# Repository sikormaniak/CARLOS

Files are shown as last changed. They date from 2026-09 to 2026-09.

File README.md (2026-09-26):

# CARLOS

Repozytorium projektowe robota mobilnego z napędem mecanum, zrealizowanego w ramach pracy dyplomowej. Zawiera schematy elektroniczne i modele 3D (Altium Designer), pliki produkcyjne PCB (Gerber) oraz projekt oprogramowania wbudowanego (ESP-IDF).

## Struktura repozytorium

```
CARLOS/
├── design/     # schematy Altium Designer, modele 3D oraz dokumentacja PDF 3D
├── gerber/     # pliki produkcyjne PCB (Gerber)
└── software/   # oprogramowanie wbudowane (ESP-IDF)
```

## `design/` -- Altium Designer

Folder zawiera schematy elektroniczne, pliki 3D płytek oraz ich podgląd w formacie PDF 3D.

### Główny obwód drukowany

- `schemat.SchDoc` -- Schemat główny, integrujący wszystkie moduły
  - `ARGB.SchDoc` -- Sterowanie diodami adresowalnymi ARGB
  - `MCU_unit.SchDoc` -- Jednostka mikrokontrolera Waveshare ESP32-P4-Module
  - `connectors.SchDoc` -- Złącza zewnętrzne oraz zworki konfiguracyjne
  - `audio.SchDoc` -- Obsługa buzzera, głośnika oraz mikrofonu
  - `IMU.SchDoc` -- Konfiguracja żyroskopu oraz magnetometru
  - `Motor_SCH.SchDoc` -- Blok łączący funkcjonalność dla 4 silników szczotkowych
    - `DRV8837CDSGR.SchDoc` -- Konfiguracja mostka H -- DRV8837CDSGR
  - `microsd_card.SchDoc` -- Interfejs karty microSD
  - `USB_HS.SchDoc` -- Interfejs USB High-Speed
  - `CH342F.SchDoc` -- Konwerter USB-UART CH342F
  - `Power_block.SchDoc` -- LDO dla 5V oraz przetwornica BUCK dla 3,3V

### Doker baterii

- `main_IP5353.SchDoc` -- Schemat główny dokera

### Pliki 3D

- Modele 3D płytek PCB
- Dokumentacja PDF 3D -- interaktywny podgląd płytek, możliwy do otwarcia w Adobe Acrobat Reader

## `gerber/` -- Pliki wykonawcze

Zweryfikowane zamówienie w [JLCPCB](https://jlcpcb.com).

- `carlos_v0.1` -- Pliki gerber dla głównego PCB
- `slim_v3.2` -- Pliki gerber dla dokera baterii

## `software/` -- Oprogramowanie ESP-IDF

- `CMakeLists.txt` -- główny plik konfiguracyjny projektu
- `sdkconfig.defaults` -- domyślna konfiguracja projektu (docelowy mikrokontroler, dane sieci WiFi, adres i port agenta micro-ROS, przypisanie pinów silników)
- `partitions.csv` -- niestandardowa tabela partycji pamięci flash
- `main/CMakeLists.txt` -- plik konfiguracyjny komponentu głównego
- `main/Kconfig.projbuild` -- definicja opcji konfiguracyjnych projektu dostępnych w `menuconfig` (piny GPIO oraz grupy MCPWM dla czterech silników)
- `main/idf_component.yml` -- deklaracja zależności projektu, w tym komponentu `micro_ros_espidf_component`
- `main/robot_main.c` -- kod źródłowy realizujący obsługę odbiornika RC (protokół CRSF), kinematykę odwrotną napędu mecanum, sterowanie silnikami (PWM) oraz integrację z systemem micro-ROS

### Konfiguracja pinów silników

Przypisanie pinów nie jest zapisane na stałe w kodzie -- definiuje je `main/Kconfig.projbuild`, a wartości trafiają do `sdkconfig` jako makra `CONFIG_WHEEL_*`. Zmiana pinów nie wymaga edycji kodu źródłowego:

```bash
idf.py menuconfig   # menu: CARLOS - piny silników
```

| Koło | IN1 | IN2 | Grupa MCPWM |
|---|-----|-----|---|
| Przednie lewe (FL) | GPIO 5  | GPIO 20 | 0 |
| Przednie prawe (FR) | GPIO 32 | GPIO 33 | 0 |
| Tylne lewe (BL) | GPIO 3  | GPIO 4  | 1 |
| Tylne prawe (BR) | GPIO 1  | GPIO 2  | 1 |

> Zmiany w `sdkconfig.defaults` są uwzględniane dopiero po usunięciu pliku `sdkconfig` lub wykonaniu `idf.py fullclean`.

### Wymagania

- ESP-IDF v5.5 z toolchainem dla ESP32-P4
- Linux lub WSL (Ubuntu)

Pakiety systemowe (kompilator hosta, potrzebny do zbudowania narzędzi micro-ROS):

```bash
sudo apt update
sudo apt install build-essential git
```

Pakiety Pythona dla micro-ROS (colcon i zależności), instalowane w środowisku Pythona ESP-IDF:

```bash
. $IDF_PATH/export.sh
python -m pip install catkin_pkg lark-parser colcon-common-extensions empy==3.3.4
```

> Wersja `empy==3.3.4` jest wymagana -- nowsze wersje (4.x) nie są kompatybilne z budowaniem micro-ROS.

Weryfikacja instalacji:

```bash
python -c "import catkin_pkg, lark, em, colcon_core; print('OK')"
```

### Budowanie projektu

```bash
cd software
idf.py set-target esp32p4
idf.py menuconfig   # konfiguracja WiFi, adresu agenta micro-ROS oraz pinów silników
idf.py build flash monitor
```

Pierwsze budowanie trwa kilka minut -- komponent micro-ROS jest pobierany automatycznie do `managed_components/` i kompilowany jako biblioteka `libmicroros.a`. Kolejne buildy korzystają z gotowej biblioteki.

> Główny `CMakeLists.txt` zawiera poprawkę zmiennej `PATH`, która usuwa z niej katalogi z asemblerami toolchainów ESP. Bez niej systemowy `gcc` używany przez micro-ROS wybierałby niewłaściwy asembler (`as: unrecognized option '--64'`).

W razie ponownego budowania micro-ROS od zera:

```bash
rm -rf build managed_components/micro-ros__micro_ros_espidf_component/micro_ros_dev managed_components/micro-ros__micro_ros_espidf_component/micro_ros_src
idf.py build
```

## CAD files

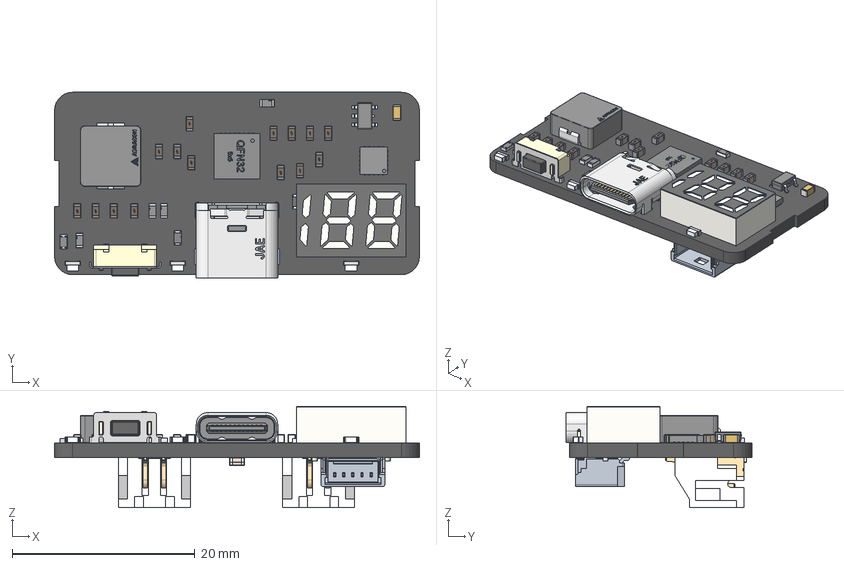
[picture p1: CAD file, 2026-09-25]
design/Battery Docker/Docker.stp
40.0 x 20.3 x 11.1 mm
RES0603 x 2
BODY-SOT
LEAD-SOT x 5
LEAD-DUMMY
188???
Samsung logo x 16
Panasonic Logo
ThermalPin
PinsArrayLR
PinsArrayTB
RT0603BRD07104KL_Ceramic
RT0603BRD07104KL_Terminal x 2
RT0603BRD07104KL_Coating
RT0603BRD07104KL_Logo
Yageo Logo x 5
QFN32-5x5
terminal
logo
TL 3330 Tactile Button
JST-S2B-PH-SM4-TB x 2
K3D-DX07S024JJ2-V1_JAE_Proprietary
Notch
pins

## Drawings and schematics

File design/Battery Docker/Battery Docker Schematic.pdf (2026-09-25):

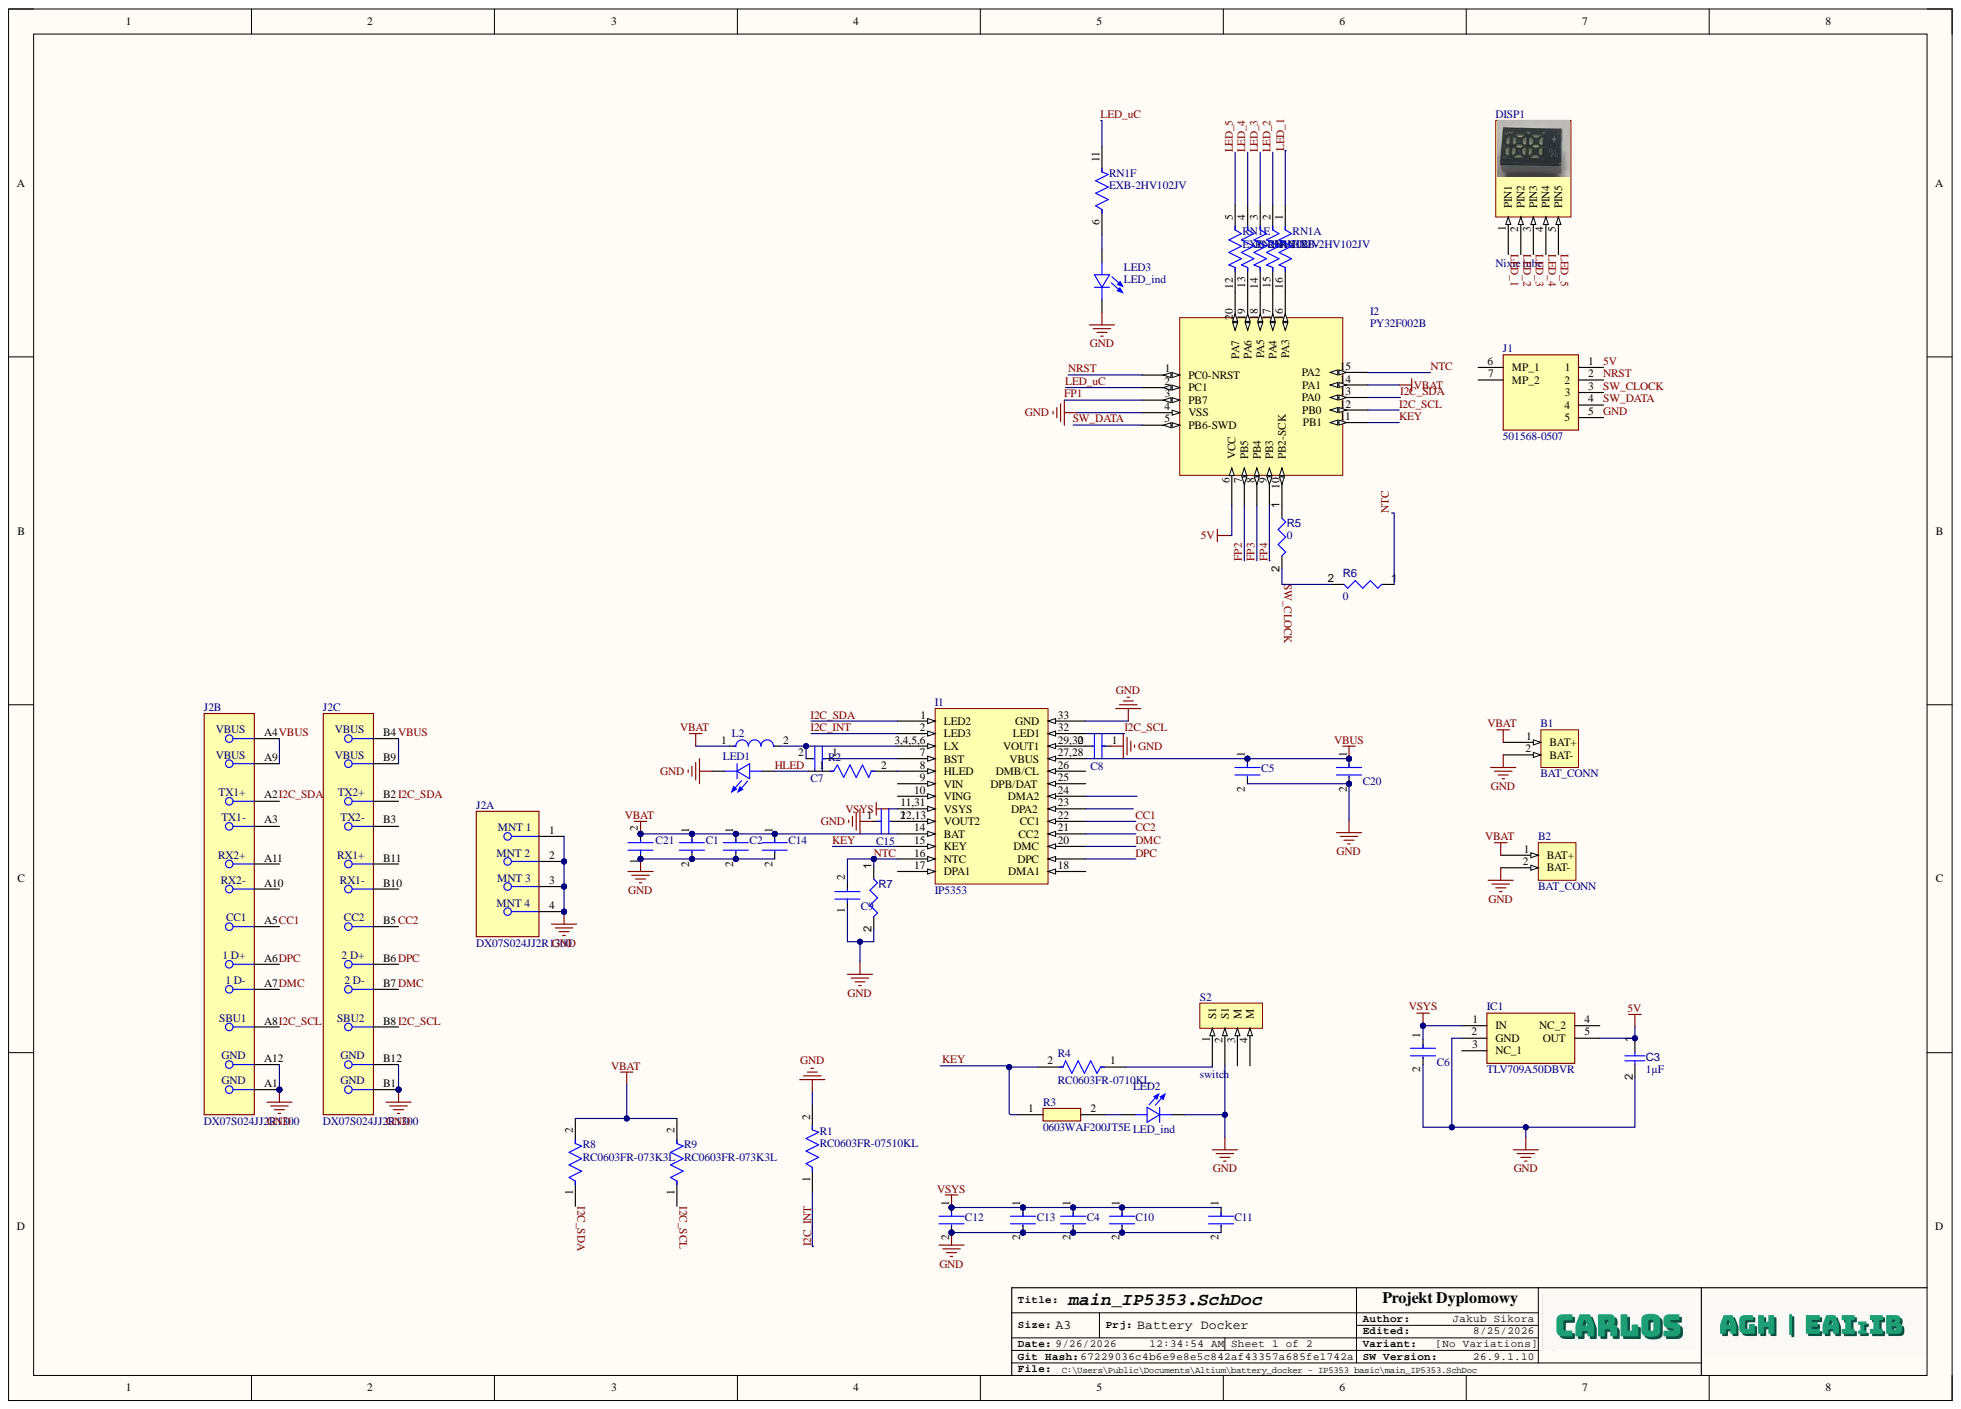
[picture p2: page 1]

12:34:54 AM Date: | Variant: [No Variations] | * 9/26/2026

Git Hash:67229036c4b6e9e8e5c842af43357a685fe1742a

File: C:\Users\Public\Documents\Altium\battery_docker - IP5353 basic\main_IP5353.SchDoc

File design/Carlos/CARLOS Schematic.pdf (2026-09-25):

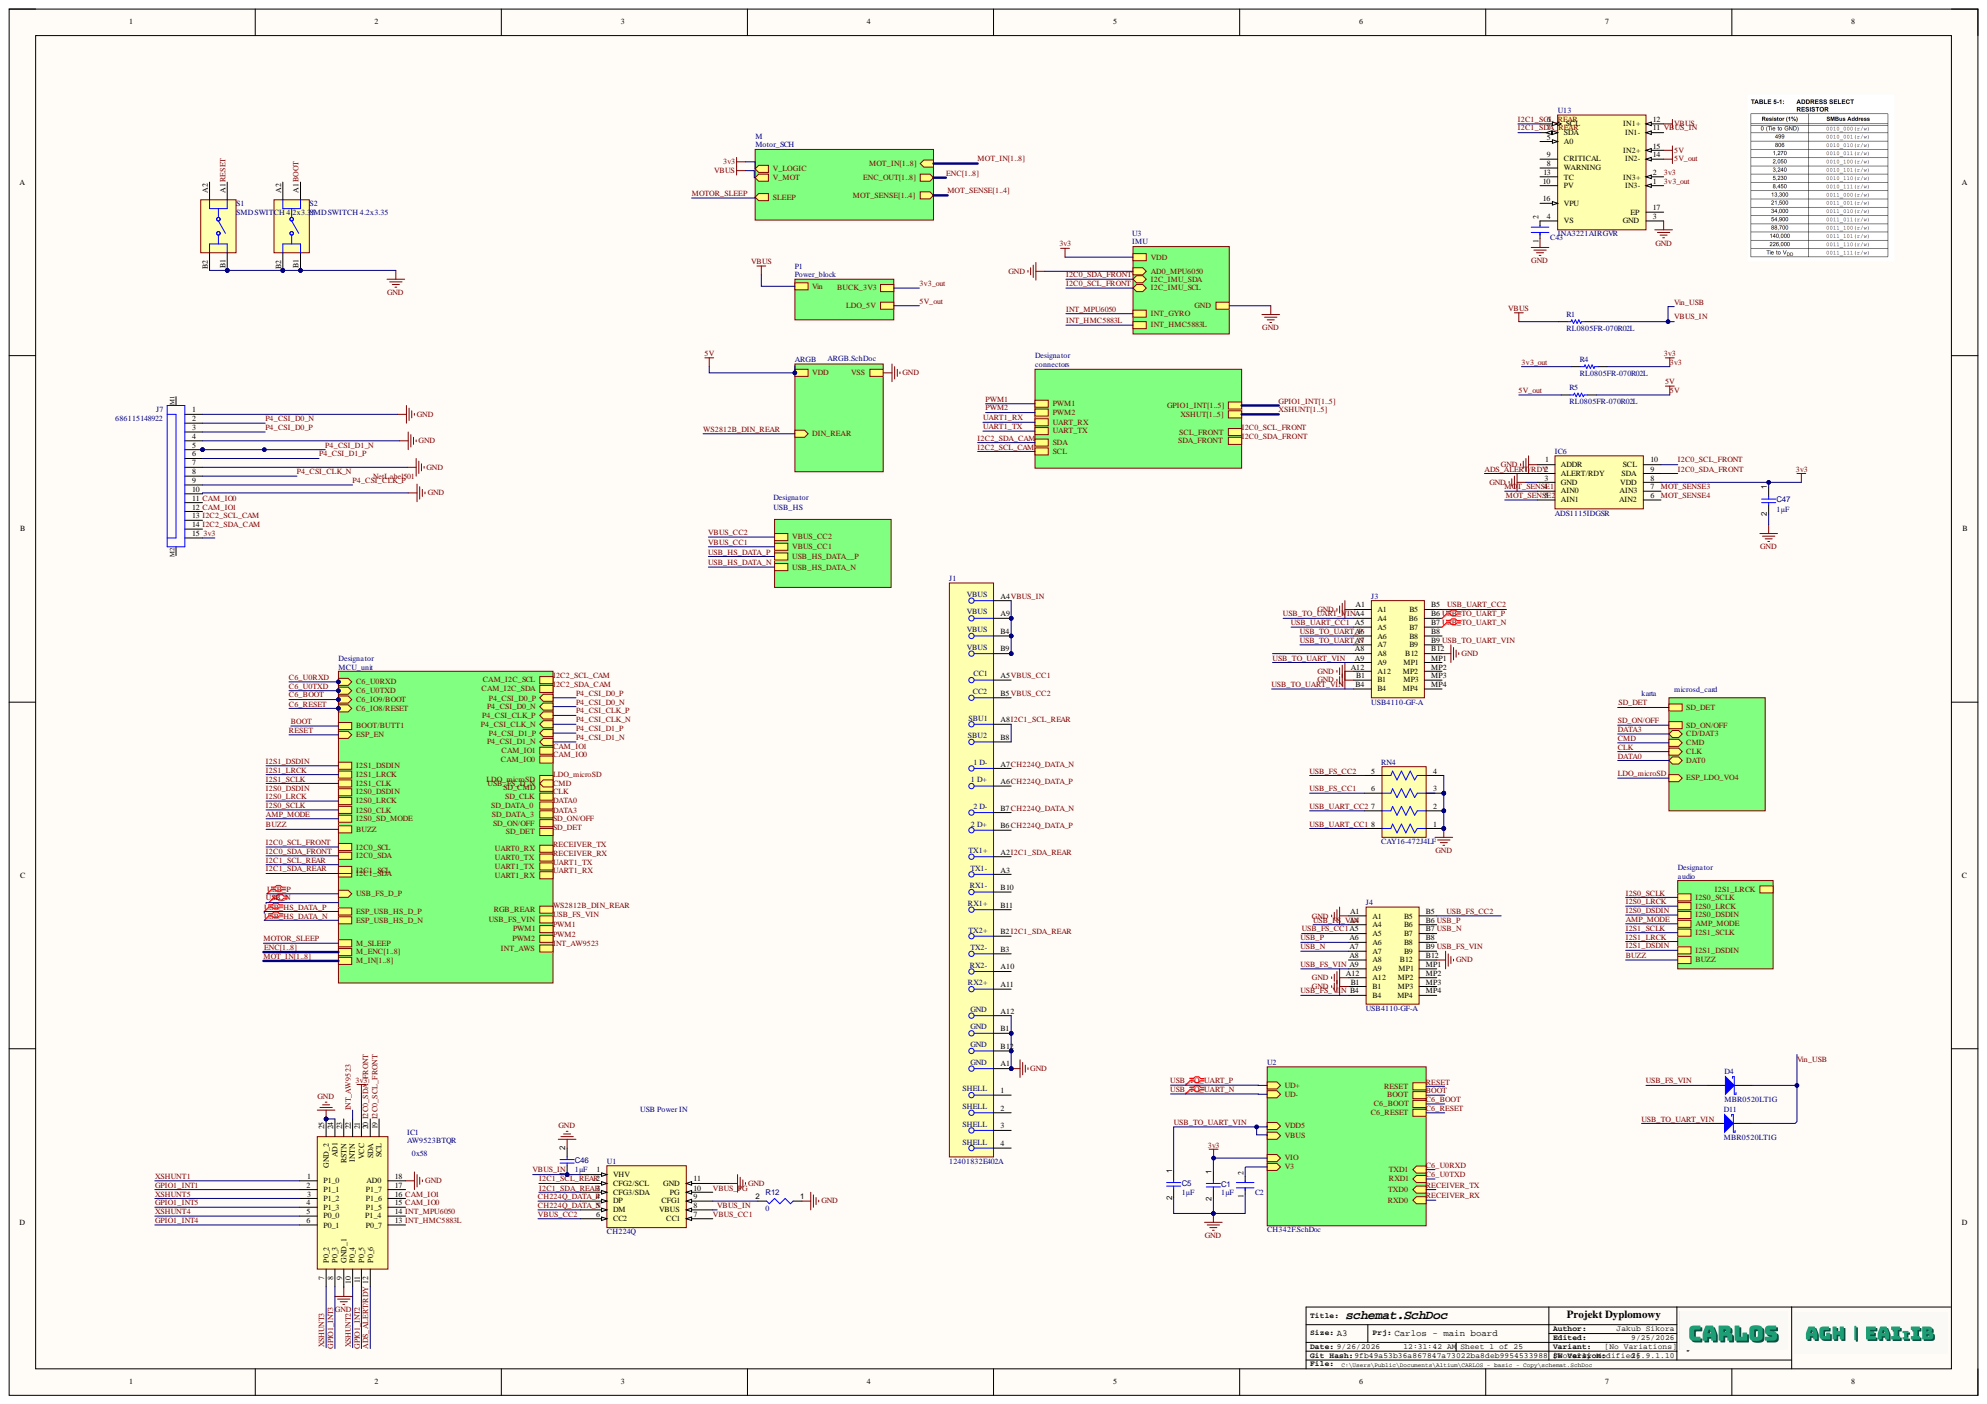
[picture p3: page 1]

Size: A3 | Prj: Carlos - main board | Author: Jakub Sikora

Date: | | Variant: [No Variations]

File: C:\Users\Public\Documents\Altium\CARLOS - basic - Copy\schemat.SchDoc

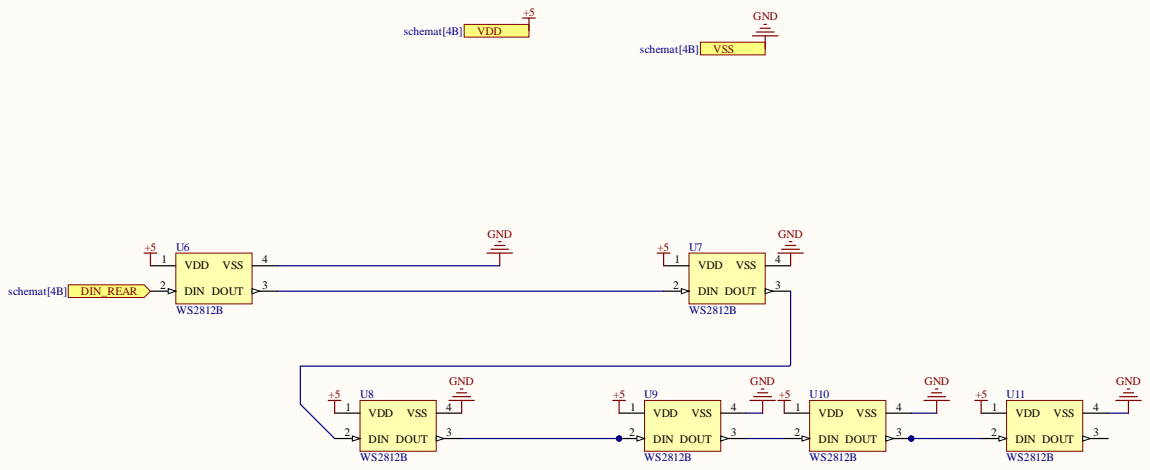
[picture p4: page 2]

Prj: Carlos - main board

Git Hash: 9fb49a53b36a867847a73022ba8deb9954533988

File: C:\Users\Public\Documents\Altium\CARLOS - basic - Copy\ARGB.SchDoc

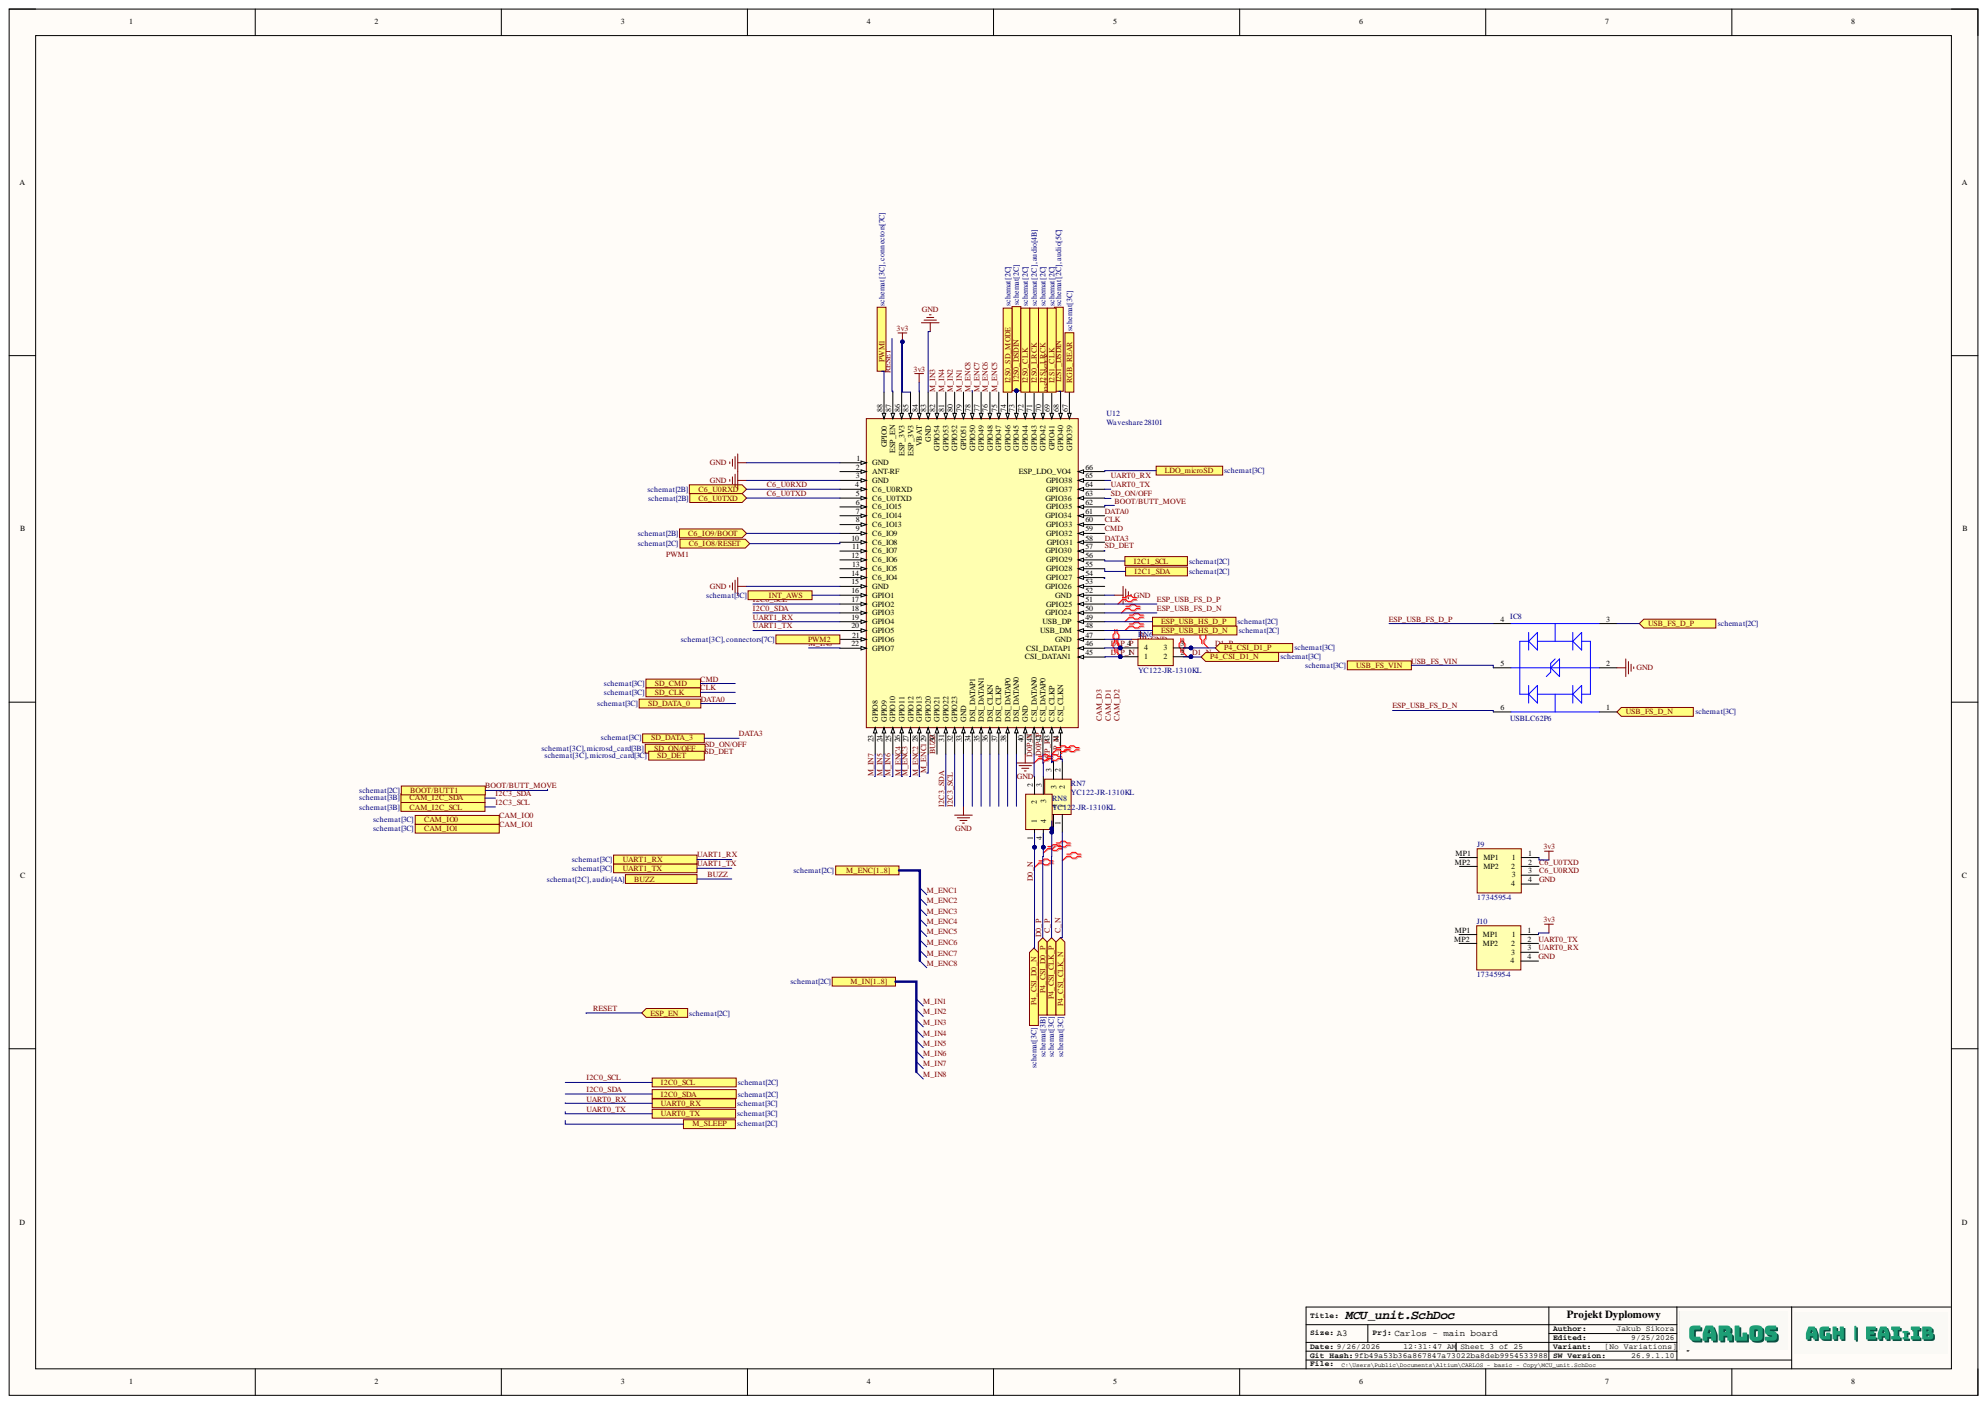
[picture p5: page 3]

Prj: Carlos - main board

Git Hash:9fb49a53b36a867847a73022ba8deb9954533988
File: C:\Users\Public\Documents\Altium\CARLOS - basic - Copy\MCU_unit.SchDoc

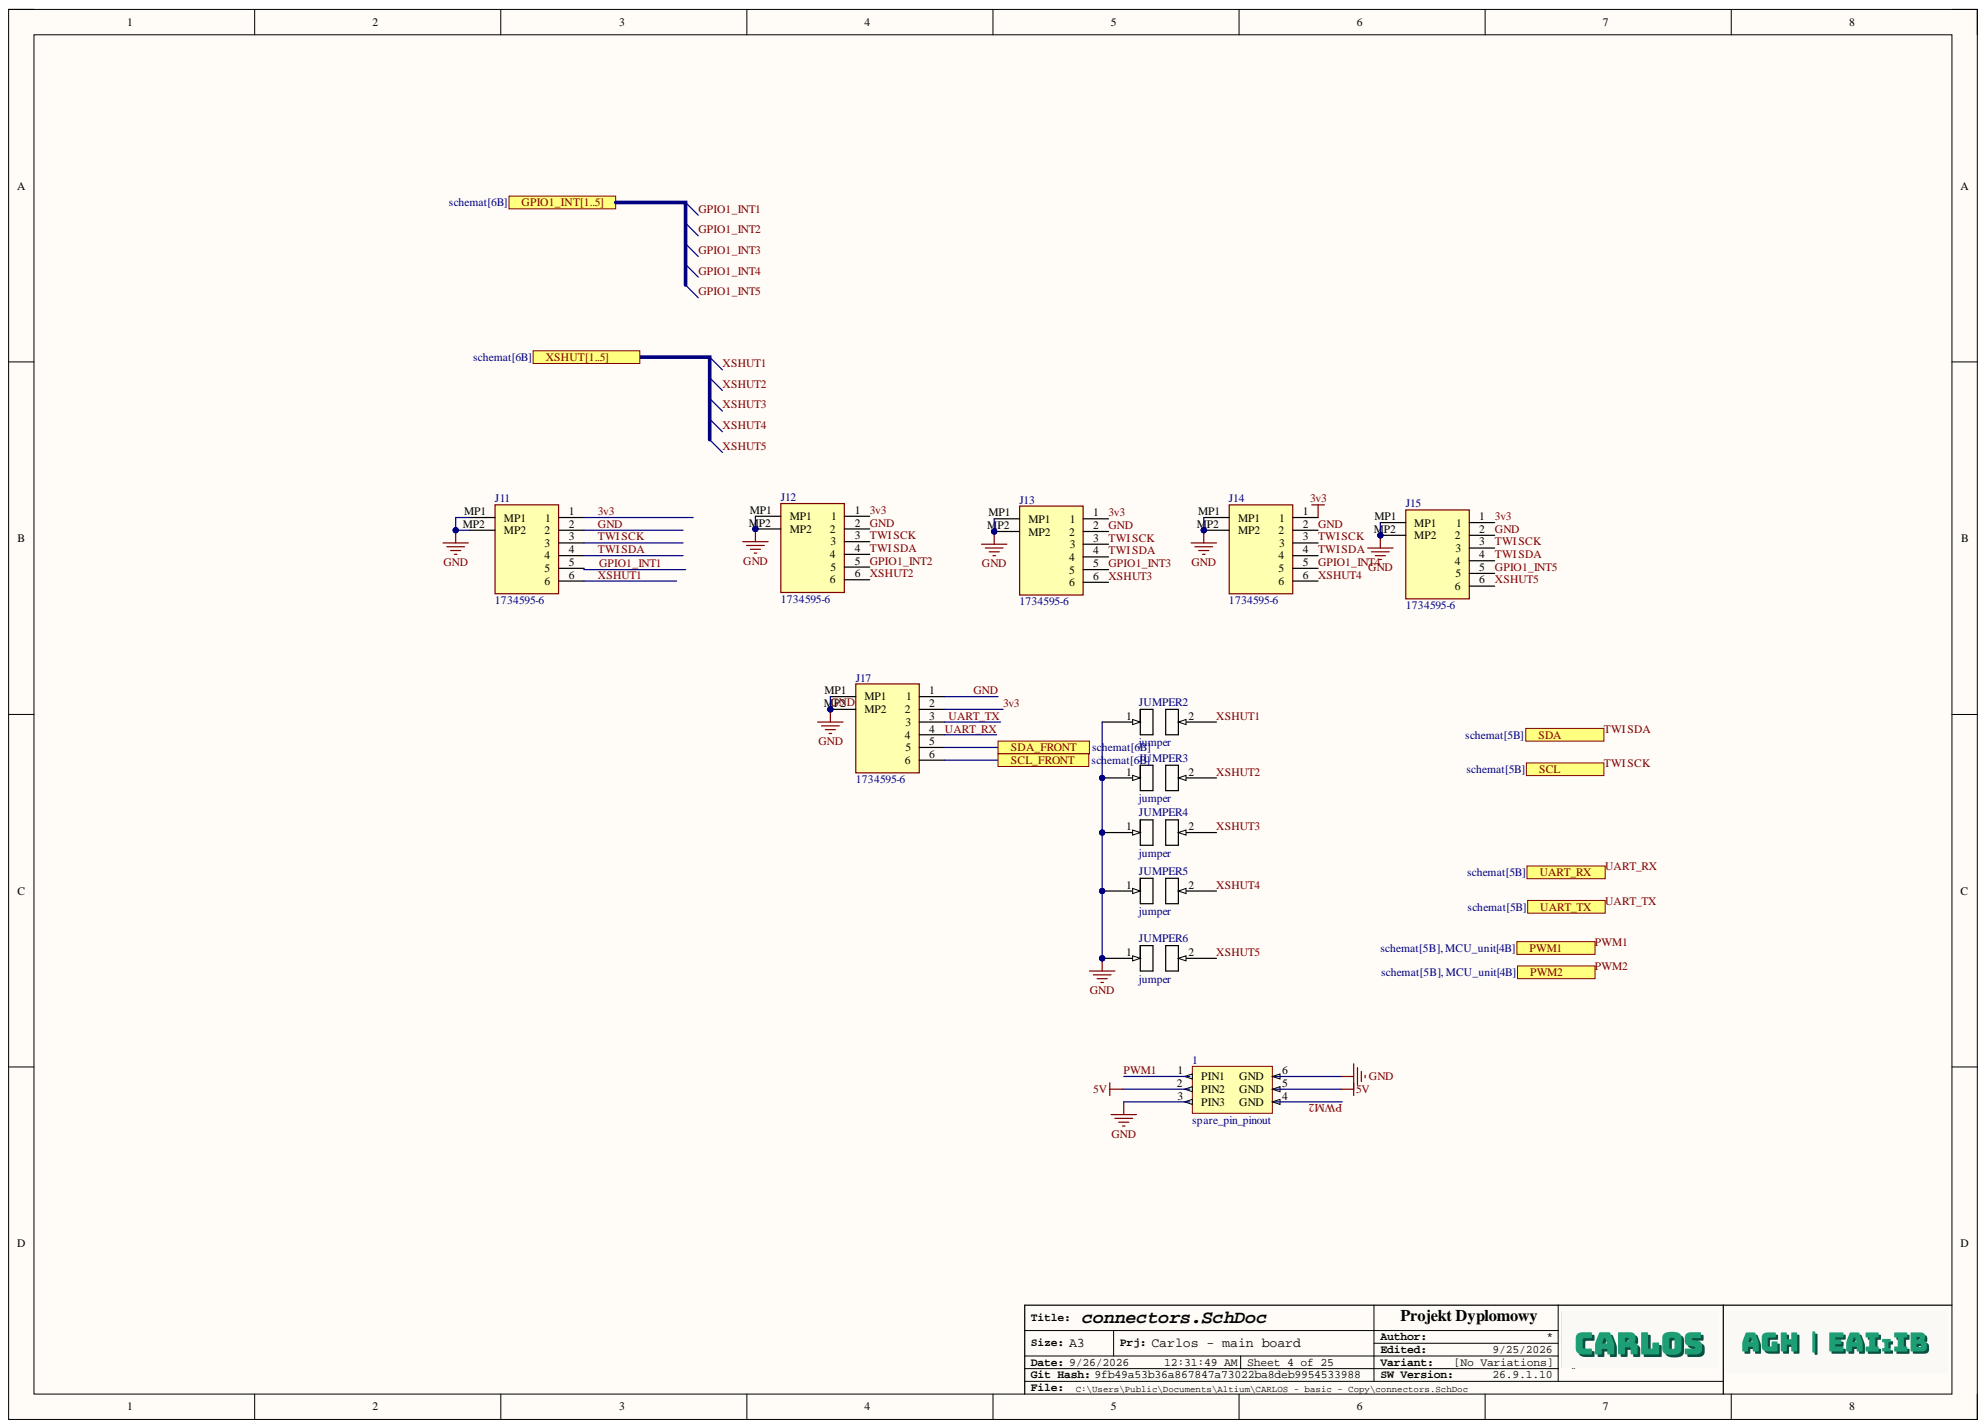
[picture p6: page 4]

Prj: Carlos - main board

File: C:\Users\Public\Documents\Altium\CARLOS - basic - Copy\connectors.SchDoc

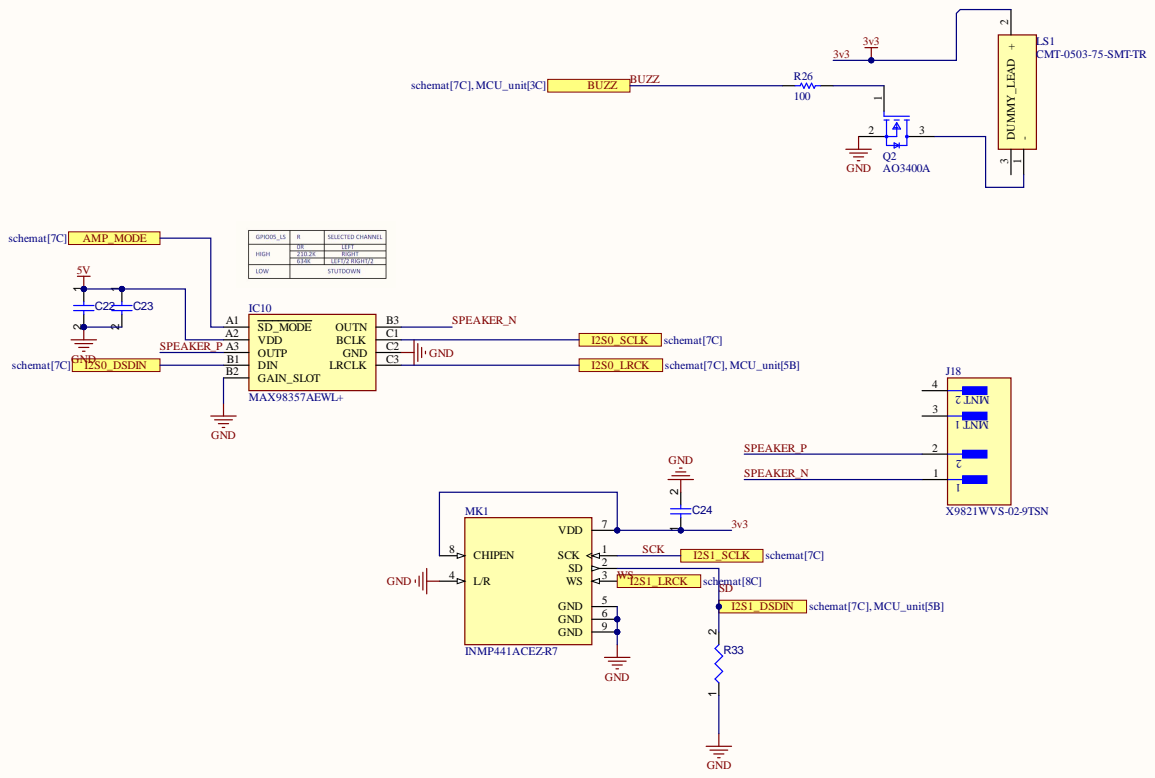
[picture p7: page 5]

Prj: Carlos - main board

File: C:\Users\Public\Documents\Altium\CARLOS - basic - Copy\audio.SchDoc

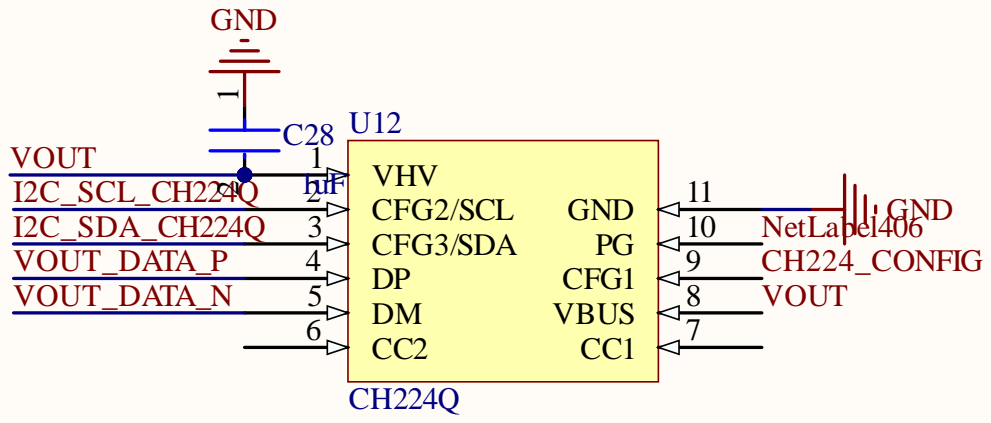
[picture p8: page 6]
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

: C:\Users\Public\Documents\Altium\CARLOS - basic - Copy\CH224Q.SchDoc

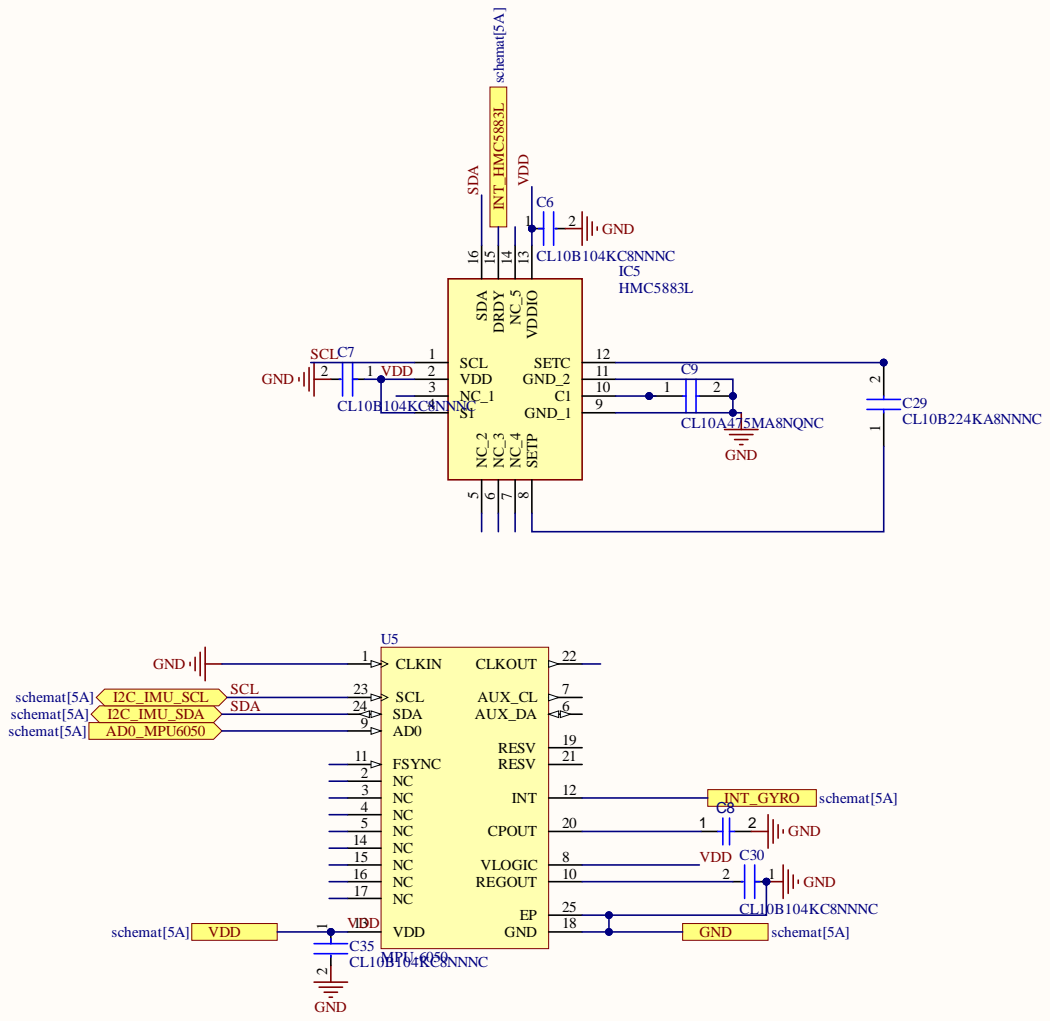
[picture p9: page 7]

VDD 2 NC_1 3 S1 4 | C9

Prj: Carlos - main board

File: C:\Users\Public\Documents\Altium\CARLOS - basic - Copy\IMU.SchDoc

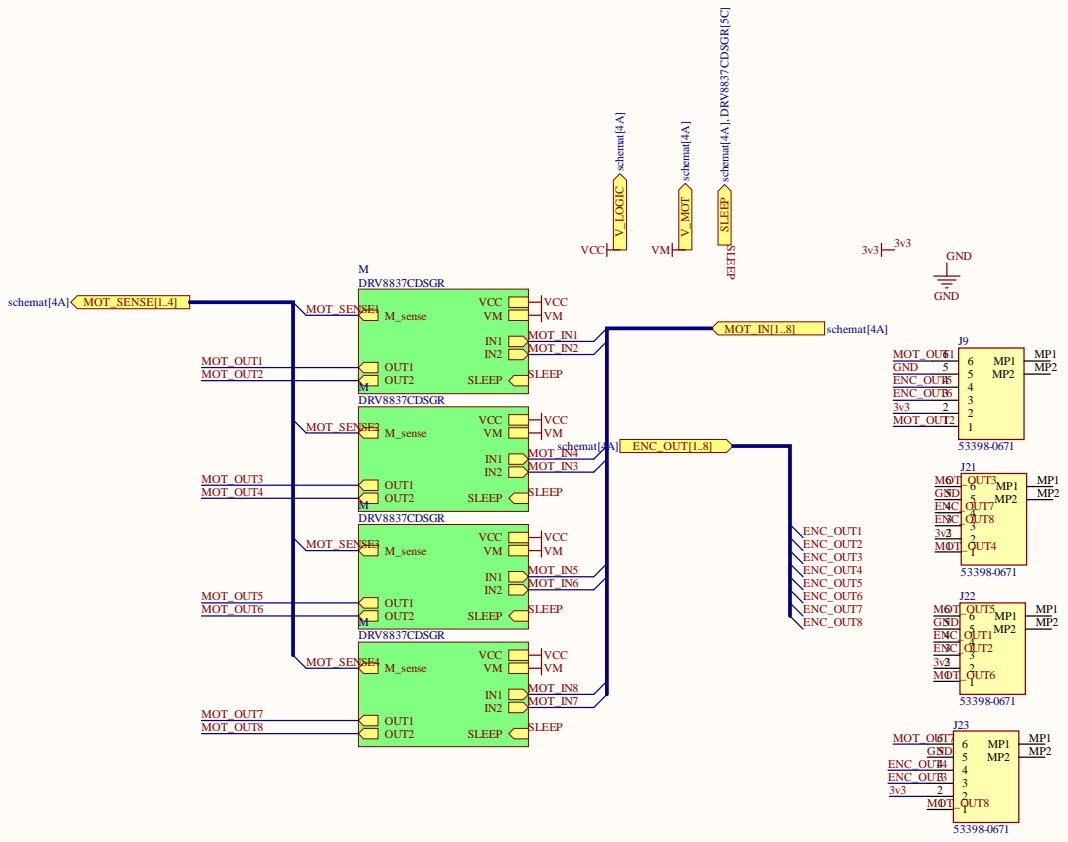
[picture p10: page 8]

Prj: Carlos - main board

File: C:\Users\Public\Documents\Altium\CARLOS - basic - Copy\Motor_SCH.SchDoc

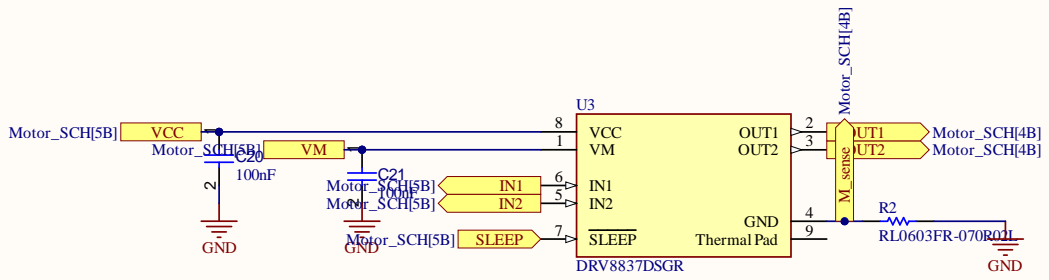
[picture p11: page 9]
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

: C:\Users\Public\Documents\Altium\CARLOS - basic - Copy\DRV8837CDSGR.SchDoc

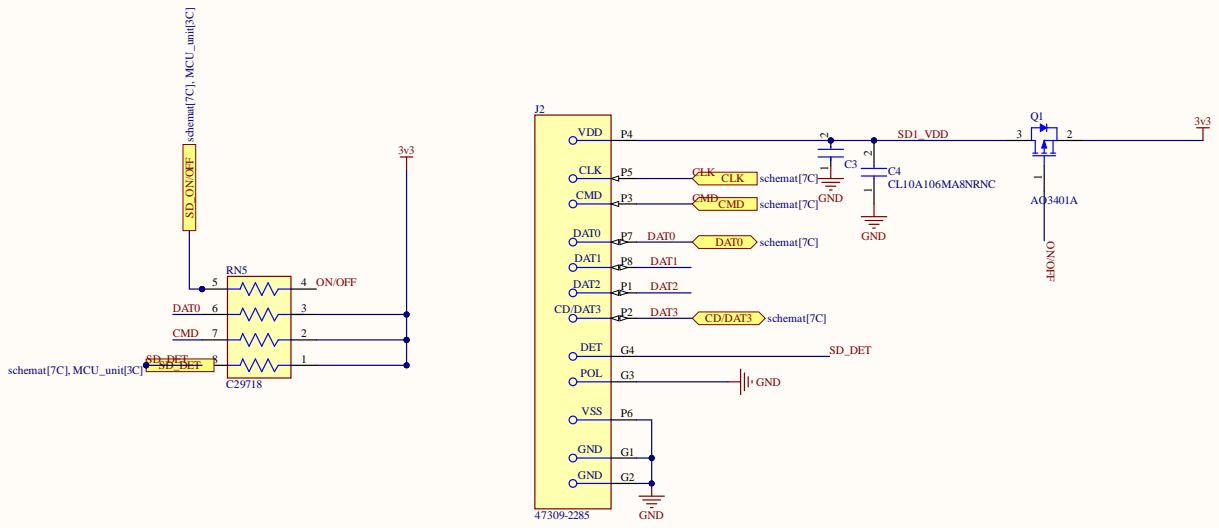
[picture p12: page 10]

MD VDD CLK VSS DAT0 DAT1

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

: C:\Users\Public\Documents\Altium\CARLOS - basic - Copy\microsd_card.SchDoc

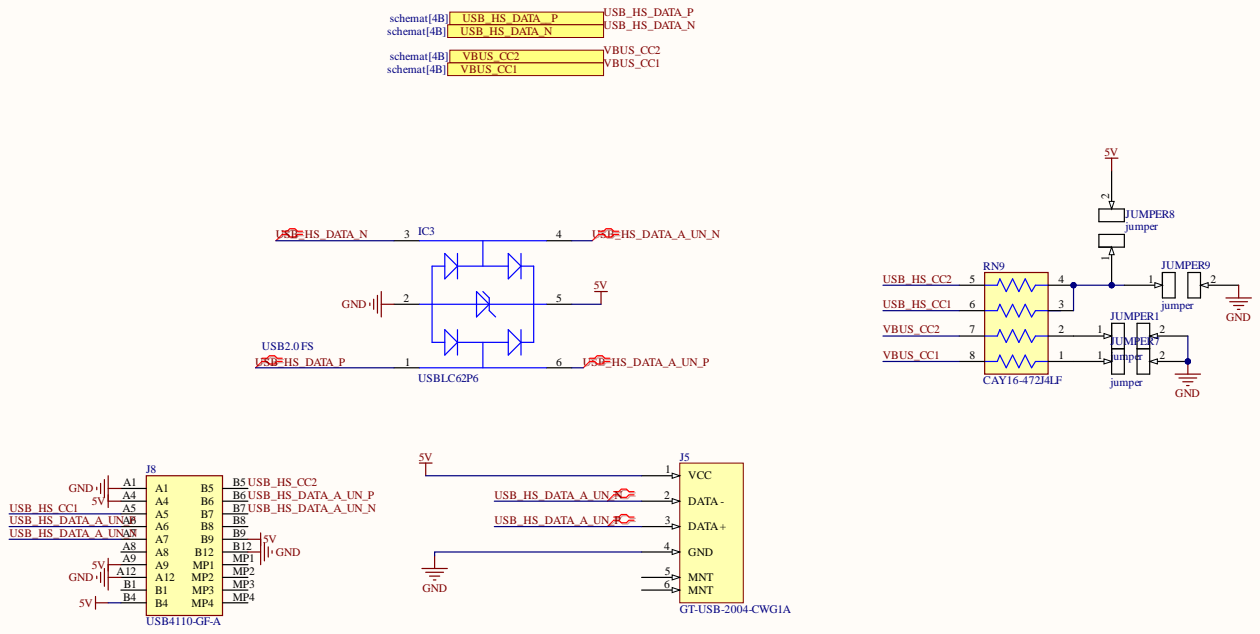
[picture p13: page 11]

A1 A1 | USB_HS_DATA_A_UN_N | DATA - 2

A5 A5 | USB_HS_DATA_A_UN_P | DATA+ 3

Prj: Carlos - main board

File: C:\Users\Public\Documents\Altium\CARLOS - basic - Copy\USB_HS.SchDoc


Prj: Carlos - main board

File: C:\Users\Public\Documents\Altium\CARLOS - basic - Copy\CH342F.SchDoc


Prj: Carlos - main board

File: C:\Users\Public\Documents\Altium\CARLOS - basic - Copy\Power_block.SchDoc

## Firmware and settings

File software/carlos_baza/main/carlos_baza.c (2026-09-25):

/*
 * Sterowanie platformą mecanum (4x N20, 4x DRV8833) z dwoma
 * niezależnymi źródłami komend prędkości:
 *
 *   1) micro-ROS  -> subskrybent /cmd_vel (geometry_msgs/msg/Twist)
 *   2) ELRS/CRSF  -> odbiornik RC podłączony przez UART (kanał zapasowy /
 *                    ręczne sterowanie / failsafe, NIEZALEŻNY od WiFi)
 *
 * Priorytet: gdy z odbiornika RC napływają świeże ramki ORAZ przełącznik
 * (kanał AUX, domyślnie CH5) jest w pozycji "override", pilot ma
 * pierwszeństwo nad komendami z ROS 2 -- to standardowe zabezpieczenie
 * (failsafe) w systemach zdalnie sterowanych. W przeciwnym razie robot
 * jedzie zgodnie z ostatnią komendą /cmd_vel; jeśli obie komendy są
 * nieaktualne (timeout), robot się zatrzymuje.
 *
 * UWAGA -- WERSJA BEZ ENKODERÓW:
 * Ze względu na niedobór dostępnych pinów GPIO enkodery kwadraturowe
 * (PCNT) oraz oparta na nich pętla regulacji PID zostały usunięte.
 * Sterowanie silnikami jest teraz w układzie otwartym (feedforward) --
 * zadana prędkość koła (rad/s) jest bezpośrednio, liniowo przeliczana
 * na wypełnienie PWM względem zakładanej maksymalnej prędkości obrotowej
 * silnika (MAX_WHEEL_SPEED_RAD_S), bez żadnej korekcji na podstawie
 * rzeczywiście zmierzonej prędkości. Konsekwencje praktyczne:
 *   - brak kompensacji różnic między silnikami (tolerancje produkcyjne,
 *     różne obciążenie każdego koła) -- robot może ciągnąć w bok,
 *   - brak kompensacji spadku napięcia baterii w czasie,
 *   - brak możliwości precyzyjnej odometrii (nie ma zliczania impulsów).
 *
 * WSZYSTKIE WARTOŚCI OZNACZONE "-- DOPASOWAĆ" WYMAGAJĄ WERYFIKACJI
 * WZGLĘDEM RZECZYWISTEGO SPRZĘTU PRZED URUCHOMIENIEM.
 */
#include "sdkconfig.h"
#include <stdio.h>
#include <string.h>
#include <math.h>
#include <inttypes.h>

#include "freertos/FreeRTOS.h"
#include "freertos/task.h"
#include "freertos/semphr.h"
#include "esp_log.h"
#include "esp_err.h"

#include "driver/uart.h"
#include "bdc_motor.h"

#include <rcl/rcl.h>
#include <rclc/rclc.h>
#include <rclc/executor.h>
#include <geometry_msgs/msg/twist.h>
#include <std_msgs/msg/string.h>
#include <rmw_microros/rmw_microros.h>
#include <uros_network_interfaces.h>

static const char *TAG = "robot";

/* ==========================================================================
 *  Makra pomocnicze micro-ROS
 * ========================================================================== */
#define RCCHECK(fn) do { \
    rcl_ret_t temp_rc = fn; \
    if ((temp_rc != RCL_RET_OK)) { \
        ESP_LOGE(TAG, "Blad RCL w linii %d: %d. Restart.", __LINE__, (int)temp_rc); \
        vTaskDelete(NULL); \
    } \
} while (0)

#define RCSOFTCHECK(fn) do { \
    rcl_ret_t temp_rc = fn; \
    if ((temp_rc != RCL_RET_OK)) { \
        ESP_LOGW(TAG, "Blad RCL (niekrytyczny) w linii %d: %d", __LINE__, (int)temp_rc); \
    } \
} while (0)

/* ==========================================================================
 *  Parametry PWM / MCPWM (sterowanie DRV8833 przez wejścia IN1/IN2)
 * ========================================================================== */
#define BDC_MCPWM_TIMER_RESOLUTION_HZ  10000000    // 10 MHz -> 1 tick = 0.1 us
#define BDC_MCPWM_FREQ_HZ              25000       // 25 kHz PWM
#define BDC_MCPWM_DUTY_TICK_MAX        (BDC_MCPWM_TIMER_RESOLUTION_HZ / BDC_MCPWM_FREQ_HZ)

/* ==========================================================================
 *  Sterowanie otwarte (feedforward) -- bez enkoderów / PID
 * ========================================================================== */
#define CONTROL_LOOP_PERIOD_MS         20          // 50 Hz

// Maksymalna prędkość obrotowa koła (rad/s) przy pełnym wypełnieniu PWM,
// odpowiadająca prędkości obrotowej wyjścia przekładni N20 bez obciążenia.
// -- DOPASOWAĆ na podstawie danych katalogowych silnika N20 (RPM przy
// zasilaniu nominalnym) przeliczonych na rad/s: rad/s = RPM * 2*pi/60.
#define MAX_WHEEL_SPEED_RAD_S          44.0f       // 420 RPM -> 43.98 rad/s, ale w praktyce przy obciążeniu i spadku napięcia

/* ==========================================================================
 *  Geometria platformy mecanum (wzory z rozdziału "Ruch")
 * ========================================================================== */
#define WHEEL_RADIUS_M                 0.029f      // 58 mm średnicy koła -> 29 mm promienia
#define WHEEL_LX_M                     0.040f      // 40 mm odległości osi koła od środka platformy wzdłuż osi X (przód-tył)
#define WHEEL_LY_M                     0.0725f      // 72.5 mm odległości osi koła od środka platformy wzdłuż osi Y (lewo-prawo)

/* ==========================================================================
 *  Limity prędkości platformy (skalowanie wychyleń drążków RC)
 * ========================================================================== */
#define MAX_LINEAR_SPEED_MPS           2.0f        // -- DOPASOWAĆ
#define MAX_ANGULAR_SPEED_RADPS        8.0f        // -- DOPASOWAĆ (teoretyczny sufit z geometrii ~11.3 rad/s;
                                                    // 8.0 daje solidny margines duty na pokonanie oporu obrotu
                                                    // w miejscu, ktory jest wiekszy niz przy jezdzie na wprost)

/* ==========================================================================
 *  Bezpieczeństwo -- timeouty utraty łączności (failsafe)
 * ========================================================================== */
#define CRSF_LINK_TIMEOUT_MS           500         // po tym czasie RC uznawane za "martwe"
#define CMD_VEL_TIMEOUT_MS             1000        // po tym czasie /cmd_vel uznawane za "martwe"

typedef enum {
    WHEEL_FL = 0,
    WHEEL_FR,
    WHEEL_BL,
    WHEEL_BR,
    WHEEL_COUNT,
} wheel_id_t;

static const char *wheel_name[WHEEL_COUNT] = { "FL", "FR", "BL", "BR" };

/* Piny DRV8833 -- DOPASOWAĆ do rzeczywistego PCB */
typedef struct {
    int pwm_in1_gpio;
    int pwm_in2_gpio;
    int mcpwm_group_id;
} wheel_pin_config_t;

static const wheel_pin_config_t wheel_pins[WHEEL_COUNT] = {
    [WHEEL_FL] = { .pwm_in1_gpio = CONFIG_WHEEL_FL_IN1_GPIO, .pwm_in2_gpio = CONFIG_WHEEL_FL_IN2_GPIO, .mcpwm_group_id = CONFIG_WHEEL_FL_MCPWM_GROUP },
    [WHEEL_FR] = { .pwm_in1_gpio = CONFIG_WHEEL_FR_IN1_GPIO, .pwm_in2_gpio = CONFIG_WHEEL_FR_IN2_GPIO, .mcpwm_group_id = CONFIG_WHEEL_FR_MCPWM_GROUP },
    [WHEEL_BL] = { .pwm_in1_gpio = CONFIG_WHEEL_BL_IN1_GPIO, .pwm_in2_gpio = CONFIG_WHEEL_BL_IN2_GPIO, .mcpwm_group_id = CONFIG_WHEEL_BL_MCPWM_GROUP },
    [WHEEL_BR] = { .pwm_in1_gpio = CONFIG_WHEEL_BR_IN1_GPIO, .pwm_in2_gpio = CONFIG_WHEEL_BR_IN2_GPIO, .mcpwm_group_id = CONFIG_WHEEL_BR_MCPWM_GROUP },
};

typedef struct {
    bdc_motor_handle_t motor;
    float target_speed_rad_s;
} wheel_ctx_t;

static wheel_ctx_t wheels[WHEEL_COUNT];

/* ==========================================================================
 *  Wspólny stan komend prędkości (chroniony mutexem) -- dwa niezależne
 *  źródła: micro-ROS (/cmd_vel) i CRSF (RC), plus znaczniki czasu ostatniej
 *  aktualizacji, wykorzystywane do wykrywania utraty łączności.
 * ========================================================================== */
typedef struct {
    float vx;
    float vy;
    float omega;
    TickType_t last_update_tick;
} velocity_command_t;

static SemaphoreHandle_t cmd_mutex;
static velocity_command_t cmd_vel_from_ros = { 0 };
static velocity_command_t cmd_vel_from_rc  = { 0 };
static volatile bool      rc_override_switch_on = false;
static volatile bool      full_power_test_on = false;

/* ==========================================================================
 *  Biezacy aktywny tryb sterowania -- do podgladu po UART i przez ROS
 * ========================================================================== */
typedef enum {
    CONTROL_MODE_STOP = 0,   // brak swiezych komend z RC i ROS -- zatrzymanie awaryjne
    CONTROL_MODE_ROS,        // jedziemy wg /cmd_vel
    CONTROL_MODE_RC,         // pilot ma priorytet (override)
    CONTROL_MODE_FULL_POWER, // test sprzetowy -- wszystkie kola 100% do przodu, najwyzszy priorytet
} control_mode_t;

// Odczyt/zapis z dwoch roznych taskow (control_loop_task pisze, microros_task
// czyta do publikacji) -- pojedynczy int, wystarczajaco atomowy dla tego
// diagnostycznego celu, bez potrzeby dodatkowego mutexa.
static volatile control_mode_t current_control_mode = CONTROL_MODE_STOP;

static const char *control_mode_name(control_mode_t mode)
{
    switch (mode) {
        case CONTROL_MODE_RC:          return "RC";
        case CONTROL_MODE_ROS:         return "ROS";
        case CONTROL_MODE_FULL_POWER:  return "FULL_POWER";
        default:                       return "STOP";
    }
}

/* ==========================================================================
 *  Kinematyka odwrotna mecanum: (vx, vy, omega) -> omega_FL/FR/BL/BR
 * ========================================================================== */
static void mecanum_inverse_kinematics(float vx, float vy, float omega,
                                        float out_wheel_speed_rad_s[WHEEL_COUNT])
{
    const float l = WHEEL_LX_M + WHEEL_LY_M;
    out_wheel_speed_rad_s[WHEEL_FL] = (vx - vy - l * omega) / WHEEL_RADIUS_M;
    out_wheel_speed_rad_s[WHEEL_FR] = (vx + vy + l * omega) / WHEEL_RADIUS_M;
    out_wheel_speed_rad_s[WHEEL_BL] = (vx + vy - l * omega) / WHEEL_RADIUS_M;
    out_wheel_speed_rad_s[WHEEL_BR] = (vx - vy + l * omega) / WHEEL_RADIUS_M;
}

static void mecanum_set_body_velocity(float vx, float vy, float omega)
{
    float wheel_speeds[WHEEL_COUNT];
    mecanum_inverse_kinematics(vx, vy, omega, wheel_speeds);
    for (wheel_id_t id = 0; id < WHEEL_COUNT; id++) {
        wheels[id].target_speed_rad_s = wheel_speeds[id];
    }
}

/* ==========================================================================
 *  Inicjalizacja silnika dla jednego koła
 * ========================================================================== */
static void wheel_motor_init(wheel_id_t id)
{
    const wheel_pin_config_t *p = &wheel_pins[id];
    bdc_motor_config_t motor_config = {
        .pwm_freq_hz   = BDC_MCPWM_FREQ_HZ,
        .pwma_gpio_num = p->pwm_in1_gpio,
        .pwmb_gpio_num = p->pwm_in2_gpio,
    };
    bdc_motor_mcpwm_config_t mcpwm_config = {
        .group_id      = p->mcpwm_group_id,
        .resolution_hz = BDC_MCPWM_TIMER_RESOLUTION_HZ,
    };
    ESP_ERROR_CHECK(bdc_motor_new_mcpwm_device(&motor_config, &mcpwm_config, &wheels[id].motor));
    ESP_ERROR_CHECK(bdc_motor_enable(wheels[id].motor));
    ESP_LOGI(TAG, "Silnik %s zainicjalizowany (grupa MCPWM %d)", wheel_name[id], p->mcpwm_group_id);
}

/* ==========================================================================
 *  Sterowanie otwarte: zadana prędkość koła (rad/s) -> wypełnienie PWM
 * ========================================================================== */
// Minimalne wypelnienie PWM (jako udzial <0,1> BDC_MCPWM_DUTY_TICK_MAX)
// potrzebne, zeby przelamac tarcie statyczne silnika N20 + przekladni +
// rolek mecanum. Bez tego liniowe przeliczenie daje przy niskich/srednich
// wychyleniach drazka duty ktore "buczy" ale nie rusza kola -- ruch byl
// widoczny tylko w skrajnych rogach drazka (duty > ~40%).
// -- DOPASOWAC pomiarowo: podnosic recznie duty od 0% w gore (np. przez
// tymczasowy hardcode w tej funkcji) i zanotowac przy jakiej wartosci kolo
// (pod obciazeniem, zamontowane na platformie) faktycznie zaczyna sie krecic.
#define MIN_DUTY_RATIO   0.35f

static void wheel_apply_target_speed(wheel_id_t id)
{
    float target = wheels[id].target_speed_rad_s;
    float duty_ratio;

    if (fabsf(target) < 0.001f) {
        // brak komendy -- pelny STOP, bez podnoszenia duty
        duty_ratio = 0.0f;
    } else {
        // Liniowe przeliczenie <0, MAX_WHEEL_SPEED_RAD_S> na <0, 1>,
        // a nastepnie przeskalowanie tak, aby najmniejsza niezerowa
        // komenda dawala juz MIN_DUTY_RATIO, a maksymalna -- 100%.
        float raw_ratio = fabsf(target) / MAX_WHEEL_SPEED_RAD_S;
        if (raw_ratio > 1.0f) {
            raw_ratio = 1.0f;
        }
        duty_ratio = MIN_DUTY_RATIO + raw_ratio * (1.0f - MIN_DUTY_RATIO);
    }

    uint32_t duty = (uint32_t)(duty_ratio * (float)BDC_MCPWM_DUTY_TICK_MAX);

    if (target >= 0.0f) {
        ESP_ERROR_CHECK(bdc_motor_forward(wheels[id].motor));
    } else {
        ESP_ERROR_CHECK(bdc_motor_reverse(wheels[id].motor));
    }
    ESP_ERROR_CHECK(bdc_motor_set_speed(wheels[id].motor, duty));
}

/* ==========================================================================
 *  Pętla sterowania: arbitraż źródła komendy (RC > ROS > STOP) +
 *  bezpośrednie zastosowanie zadanej prędkości na każdym kole (open-loop)
 * ========================================================================== */
static void control_loop_task(void *arg)
{
    while (1) {
        TickType_t now = xTaskGetTickCount();

        xSemaphoreTake(cmd_mutex, portMAX_DELAY);
        velocity_command_t rc  = cmd_vel_from_rc;
        velocity_command_t ros = cmd_vel_from_ros;
        bool rc_switch = rc_override_switch_on;
        bool full_power = full_power_test_on;
        xSemaphoreGive(cmd_mutex);

        bool rc_fresh  = (now - rc.last_update_tick)  <= pdMS_TO_TICKS(CRSF_LINK_TIMEOUT_MS);
        bool ros_fresh = (now - ros.last_update_tick) <= pdMS_TO_TICKS(CMD_VEL_TIMEOUT_MS);

        float vx = 0.0f, vy = 0.0f, omega = 0.0f;
        control_mode_t mode;

        if (rc_fresh && full_power) {
            // Test sprzetowy -- najwyzszy priorytet, pomija kinematyke mecanum
            mode = CONTROL_MODE_FULL_POWER;
        } else if (rc_fresh && rc_switch) {
            // Pilot ma priorytet -- tryb recznego sterowania / failsafe
            vx = rc.vx; vy = rc.vy; omega = rc.omega;
            mode = CONTROL_MODE_RC;
        } else if (ros_fresh) {
            // Brak nadpisania z RC -- jedziemy wg ostatniej komendy /cmd_vel
            vx = ros.vx; vy = ros.vy; omega = ros.omega;
            mode = CONTROL_MODE_ROS;
        } else {
            // Obie komendy nieaktualne -- zatrzymanie awaryjne
            vx = 0.0f; vy = 0.0f; omega = 0.0f;
            mode = CONTROL_MODE_STOP;
        }

        if (mode != current_control_mode) {
            ESP_LOGI(TAG, "Zmiana trybu sterowania: %s -> %s",
                     control_mode_name(current_control_mode), control_mode_name(mode));
            current_control_mode = mode;
        }

        // -- DEBUG: okresowy zrzut biezacych komend, do usuniecia po diagnozie
        static TickType_t last_debug_tick = 0;
        if ((now - last_debug_tick) >= pdMS_TO_TICKS(500)) {
            last_debug_tick = now;
            ESP_LOGI(TAG, "DEBUG mode=%s vx=%.3f vy=%.3f omega=%.3f | rc(fresh=%d sw=%d fp=%d vx=%.3f vy=%.3f om=%.3f) ros(fresh=%d)",
                     control_mode_name(mode), vx, vy, omega,
                     rc_fresh, rc_switch, full_power, rc.vx, rc.vy, rc.omega,
                     ros_fresh);
        }

        if (mode == CONTROL_MODE_FULL_POWER) {
            // Wszystkie kola na 100% duty, do przodu -- test sprzetowy
            // (silniki/sterowniki/okablowanie), bez udzialu kinematyki mecanum
            for (wheel_id_t id = 0; id < WHEEL_COUNT; id++) {
                wheels[id].target_speed_rad_s = MAX_WHEEL_SPEED_RAD_S;
            }
        } else {
            mecanum_set_body_velocity(vx, vy, omega);
        }

        for (wheel_id_t id = 0; id < WHEEL_COUNT; id++) {
            wheel_apply_target_speed(id);
            ESP_LOGD(TAG, "  kolo %s: target=%.3f rad/s", wheel_name[id], wheels[id].target_speed_rad_s);
        }

        vTaskDelay(pdMS_TO_TICKS(CONTROL_LOOP_PERIOD_MS));
    }
}

/* ==========================================================================
 *  Odbiór i dekodowanie protokolu CRSF z odbiornika ELRS (UART)
 * ========================================================================== */
#define ELRS_UART_NUM       UART_NUM_1
#define ELRS_TXD_PIN        46
#define ELRS_RXD_PIN        47
#define ELRS_BAUD_RATE      420000
#define BUF_SIZE            1024

#define CRSF_SYNC_BYTE                      0xC8
#define CRSF_FRAMETYPE_RC_CHANNELS_PACKED   0x16
#define CRSF_CHANNEL_COUNT                  16

// Numeracja kanałów RC (AETR) -- DOPASOWAĆ do konfiguracji nadajnika
#define CRSF_CH_ROLL_VY     3   // kanał 1 -- ruch boczny (strafe)
#define CRSF_CH_PITCH_VX    1   // kanał 2 -- jazda przod/tyl
#define CRSF_CH_YAW_OMEGA   0   // kanał 4 -- obrot
#define CRSF_CH_AUX_OVERRIDE 4  // kanał 5 -- przelacznik trybu recznego
#define CRSF_CH_FULL_POWER_TEST 5  // kanał 6 -- test sprzetowy, wszystkie kola 100% do przodu

#define CRSF_RAW_MIN        172
#define CRSF_RAW_MAX        1811
#define CRSF_RAW_MID        992
#define CRSF_SWITCH_THRESHOLD 1500

typedef struct {
    uint8_t sync;
    uint8_t length;
    uint8_t type;
    uint8_t payload[64];
} crsf_frame_t;

typedef struct {
    uint16_t channels[CRSF_CHANNEL_COUNT];
} crsf_channels_t;

static uint8_t crsf_crc8(const uint8_t *data, uint8_t len)
{
    uint8_t crc = 0;
    for (uint8_t i = 0; i < len; i++) {
        crc ^= data[i];
        for (uint8_t j = 0; j < 8; j++) {
            crc = (crc & 0x80) ? (uint8_t)((crc << 1) ^ 0xD5) : (uint8_t)(crc << 1);
        }
    }
    return crc;
}

static void decode_rc_channels(const uint8_t *payload, crsf_channels_t *channels)
{
    channels->channels[0]  = (uint16_t)((payload[0]     | payload[1]  << 8)  & 0x07FF);
    channels->channels[1]  = (uint16_t)((payload[1]>>3  | payload[2]  << 5)  & 0x07FF);
    channels->channels[2]  = (uint16_t)((payload[2]>>6  | payload[3]  << 2  | payload[4] << 10) & 0x07FF);
    channels->channels[3]  = (uint16_t)((payload[4]>>1  | payload[5]  << 7)  & 0x07FF);
    channels->channels[4]  = (uint16_t)((payload[5]>>4  | payload[6]  << 4)  & 0x07FF);
    channels->channels[5]  = (uint16_t)((payload[6]>>7  | payload[7]  << 1  | payload[8] << 9)  & 0x07FF);
    channels->channels[6]  = (uint16_t)((payload[8]>>2  | payload[9]  << 6)  & 0x07FF);
    channels->channels[7]  = (uint16_t)((payload[9]>>5  | payload[10] << 3)  & 0x07FF);
    channels->channels[8]  = (uint16_t)((payload[11]    | payload[12] << 8)  & 0x07FF);
    channels->channels[9]  = (uint16_t)((payload[12]>>3 | payload[13] << 5)  & 0x07FF);
    channels->channels[10] = (uint16_t)((payload[13]>>6 | payload[14] << 2  | payload[15] << 10) & 0x07FF);
    channels->channels[11] = (uint16_t)((payload[15]>>1 | payload[16] << 7)  & 0x07FF);
    channels->channels[12] = (uint16_t)((payload[16]>>4 | payload[17] << 4)  & 0x07FF);
    channels->channels[13] = (uint16_t)((payload[17]>>7 | payload[18] << 1  | payload[19] << 9)  & 0x07FF);
    channels->channels[14] = (uint16_t)((payload[19]>>2 | payload[20] << 6)  & 0x07FF);
    channels->channels[15] = (uint16_t)((payload[20]>>5 | payload[21] << 3)  & 0x07FF);
}

// Przeliczenie surowej wartosci kanalu CRSF (172..1811, srodek 992) na
// znormalizowany wspolczynnik <-1.0, 1.0>
static float crsf_channel_to_normalized(uint16_t raw)
{
    float normalized = ((float)raw - CRSF_RAW_MID) / ((CRSF_RAW_MAX - CRSF_RAW_MIN) / 2.0f);
    if (normalized > 1.0f)  normalized = 1.0f;
    if (normalized < -1.0f) normalized = -1.0f;
    return normalized;
}

static void handle_rc_channels_frame(const uint8_t *payload)
{
    crsf_channels_t channels;
    decode_rc_channels(payload, &channels);

    // -- DEBUG: okresowy zrzut surowych wartosci wszystkich 16 kanalow CRSF,
    // do usuniecia po ustaleniu poprawnego mapowania kanalow
    static TickType_t last_raw_log_tick = 0;
    TickType_t now_raw = xTaskGetTickCount();
    if ((now_raw - last_raw_log_tick) >= pdMS_TO_TICKS(500)) {
        last_raw_log_tick = now_raw;
        ESP_LOGI(TAG, "RAW CH: 0=%4d 1=%4d 2=%4d 3=%4d 4=%4d 5=%4d 6=%4d 7=%4d",
                 channels.channels[0], channels.channels[1], channels.channels[2], channels.channels[3],
                 channels.channels[4], channels.channels[5], channels.channels[6], channels.channels[7]);
    }

    float vx    = crsf_channel_to_normalized(channels.channels[CRSF_CH_PITCH_VX])  * MAX_LINEAR_SPEED_MPS;
    float vy    = crsf_channel_to_normalized(channels.channels[CRSF_CH_ROLL_VY])   * MAX_LINEAR_SPEED_MPS;
    float omega = crsf_channel_to_normalized(channels.channels[CRSF_CH_YAW_OMEGA]) * MAX_ANGULAR_SPEED_RADPS;
    bool  override_on   = channels.channels[CRSF_CH_AUX_OVERRIDE]     > CRSF_SWITCH_THRESHOLD;
    bool  full_power_on  = channels.channels[CRSF_CH_FULL_POWER_TEST] > CRSF_SWITCH_THRESHOLD;

    xSemaphoreTake(cmd_mutex, portMAX_DELAY);
    cmd_vel_from_rc.vx = vx;
    cmd_vel_from_rc.vy = vy;
    cmd_vel_from_rc.omega = omega;
    cmd_vel_from_rc.last_update_tick = xTaskGetTickCount();
    rc_override_switch_on = override_on;
    full_power_test_on = full_power_on;
    xSemaphoreGive(cmd_mutex);
}

static void process_crsf_frame(const crsf_frame_t *frame)
{
    uint8_t crc_calc     = crsf_crc8(&frame->type, frame->length - 1);
    uint8_t crc_received = frame->payload[frame->length - 2];
    if (crc_calc != crc_received) {
        ESP_LOGW(TAG, "CRSF: bledny CRC (obliczony 0x%02X, odebrany 0x%02X)", crc_calc, crc_received);
        return;
    }

    if (frame->type == CRSF_FRAMETYPE_RC_CHANNELS_PACKED) {
        handle_rc_channels_frame(frame->payload);
    }
    // Pozostale typy ramek (telemetria) pominiete -- do rozbudowy w razie potrzeby
}
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
void app_main(void)
{
    ESP_LOGI(TAG, "Inicjalizacja robota: mecanum (open-loop) + CRSF + micro-ROS");

    cmd_mutex = xSemaphoreCreateMutex();

    for (wheel_id_t id = 0; id < WHEEL_COUNT; id++) {
        wheel_motor_init(id);
        wheels[id].target_speed_rad_s = 0.0f;
    }

    uart_init();

    xTaskCreate(elrs_read_task,    "elrs_read",    8192, NULL, 10, NULL);
    xTaskCreate(control_loop_task, "control_loop", 4096, NULL, 6,  NULL);
    xTaskCreate(microros_task,     "microros",     16384, NULL, 5,  NULL);
}

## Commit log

2026-09-25 Update README with project details and instructions
    Added detailed project description, including schematics, Gerber files, and software project files for the mobile robot with mecanum drive.
2026-09-25 Init data sync
    [Docker.stp]
2026-09-25 Update battery dock Gerber files version
2026-09-25 Fix Gerber file version and add installation requirements
    Updated Gerber files section and added requirements for ESP-IDF and Python packages.
2026-09-25 Added motor pin selection in menuconfig
2026-09-25 Adding motor values
2026-09-26 Update battery dock Gerber file version to slim_v3.2
    Updated the version of battery dock Gerber files in README.
